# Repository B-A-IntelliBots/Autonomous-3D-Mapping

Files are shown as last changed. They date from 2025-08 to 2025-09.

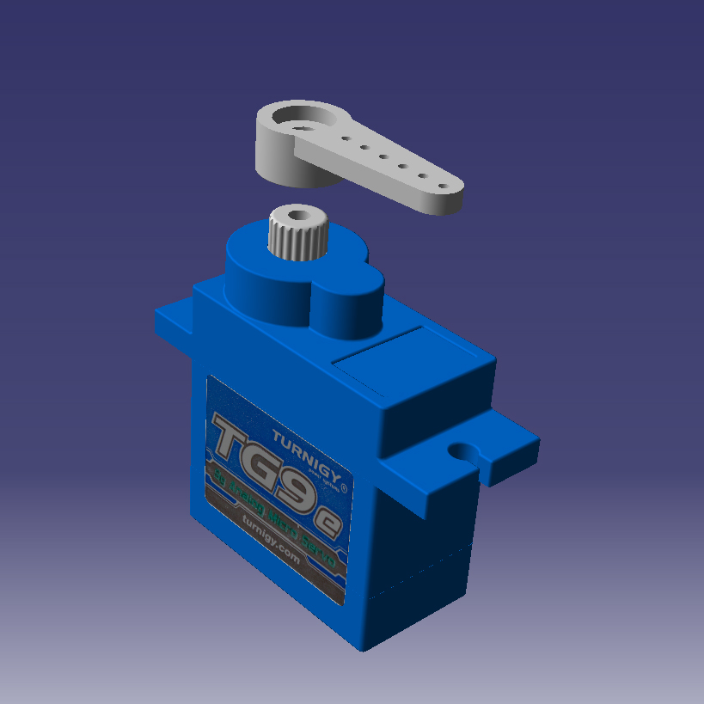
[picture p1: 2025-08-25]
src/CATIA PARTS/MICROSERVO/COMPONENT/TG9e.jpg

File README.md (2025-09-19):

<div align="center">

# Autonomous-3D-Mapping







</div>
  
## Overview
This project presents the development, modeling, and experimental validation of an
autonomous end to end indoor 3D reconstruction system using a monocular camera-
equipped differential-drive mobile robot. The goal is to control the platform through
the environment on a predefined path to capture images of the scene, then implement
the 3D reconstruction pipeline to build a virtual 3D Model of the space. A comprehensive dynamic model of the robot—encompassing mechanical and
electrical subsystems—was identified using input-output experiments and refined
via genetic algorithm optimization. The work incorporates the usage of FIR filter to
remove the noise from feedback signals (such as Encoders). The control architecture
employs a cascaded scheme with a Lyapunov-based outer loop and LQR-based inner
loop. To optimize performance metrics like path accuracy and energy efficiency, a
Predictive Neural Network (PNN) was trained to map target positions to optimal
control gains (𝐾𝑝 , 𝐾𝜃), enabling real-time adaptive control.
For the 3D reconstruction part, the hierarchical localization pipeline is implemented
to build a 3D model of the environment form a set of captured images. Empirical
benchmarking identified DISK (feature extractor) and LightGlue (matcher) as the
optimal vision components. These are fed into a reconstruction pipeline using
COLMAP and OpenMVS, producing high-quality 3D models of indoor scenes.
The system is implemented on a Raspberry Pi–Arduino platform running ROS and
validated both in simulation and on a real robot. The robot autonomously navigates
pre-defined discretized paths and captures structured image arcs at predefined waypoints.
This end-to-end framework bridges control theory with practical computer vision,
demonstrating how low-cost mobile robots can autonomously map environments
with high spatial accuracy using only monocular vision and optimized motion
planning.
> **TL;DR**: End-to-end autonomous 3D reconstruction of indoor environment using DDWMR
## ✨ Key Features
+ Integrating neural network-optimized hybrid control system
+ Deploying the optimal feature extractor and matcher—DISK and LightGlue—for dense and accurate 3D point cloud generation.
+ Identifying the robot system using "System-Identification" optimized through Genetic Algorithm
+ Filtering the Feedback signals with customized filter (FIR) for reliable localization and control.
## Demo
This video shows the end-to-end autonomous 3D reconstruction Process
<div align="center">
  <video src="https://github.com/user-attachments/assets/662caa91-467a-4c62-9c5a-49453e5b212f" controls loop></video>
</div>
<p align="center">
  <table>
    <tr>
      <!-- Left big image -->
      <td rowspan="2" width="40%">
        
      </td>
      <!-- Top row, two small images -->
      <td width="26%">
        
      </td>
      <td rowspan="2" width="34%">
        
      </td>
    </tr>
    <tr>
      <!-- Bottom row, two small images -->
      <td>
        
      </td>
    </tr>
  </table>
</p>

## Methodology

<div align="center">
  Description
</div>

### 1. Setting the Discretized Path:
Since the control algorithm is designed for a stabilization task—e.i., guiding the robot from its initial position to a target location—the first step in our project should be to define a discretized path through the relevant environment.

### 2. Navigating through the environment:
This step focuses on navigating the robot through the environment to capture images of surrounding objects. The process is carried out using the control scheme described in the following repo "https://github.com/B-A-IntelliBots/AI-optimized-LQR-Lyapunov-Control-System".

### 3. 3D Reconstrution:
This step involves constructing a 3D virtual model of the indoor environment using images captured by the robotic platform. The reconstruction process employs the ***DISK* Feature Extractor** and ***LIGHTGLUE* Feature Matcher** to achieve a highly accurate and densely detailed final output. The choice of this feature extractor–matcher combination is based on extensive comparative analysis supported by statistical metrics, as detailed in the following repository "https://github.com/B-A-IntelliBots/3D-Reconstruction".

---

## 🚀 Quick Start
### Prerequisites
- OS/Tooling: `Python ≥3.10` / `MATLAB R2014a` / `ROS1 noetic` / `CATIA V5R21`
- System deps: `cmake`
### Installation

+ #### Clone the repository:
  `$ git clone https://github.com/B-A-IntelliBots/Autonomous-3D-Mapping.git 3d-mapping`
  
---

## 📊 Results & Benchmarks
the performance of the proposed **System State-Space Identification** method—using MATLAB’s *System Identification Toolbox* in combination with a Genetic Algorithm (GA)—is validated according to the following criteria:

#### 🔹 1. Loss / Error Metrics

Quantitative performance is evaluated using:  
- **Euclidean Loss** (custom-defined residual error distance)

| Model Type | Euclidean Loss |
|---|---|
| GA-Optimized | *0.1189* |

#### 🔹 2. Computational Performance

- GA converged in **~[782] generations**  
- Execution time: **~[47 Sec]** on Intel i5 CPU
  
---

## 📁Project Structure
├── [src](https://github.com/B-A-IntelliBots/Autonomous-3D-Mapping/tree/main/src)/  # Core codes with the robot CATIA-designed components <br>
├── [data](https://github.com/B-A-IntelliBots/Autonomous-3D-Mapping/tree/main/data)/ # Sample datasets <br>
├── [results](https://github.com/B-A-IntelliBots/Autonomous-3D-Mapping/tree/main/results)/    # Plots and evaluation metrics <br>
├── README.md   # This file <br>

---

## 📖 Citation

```bibtex
@software{myproject2025,
  author    = {Ali Deeb, Bisher Alsaleh}, Supervised by: {Prof. Iyad Hatem}
  title     = {Autonomous 3D Mapping},
  year      = {2025},
  publisher = {GitHub},
  url       = {https://github.com/B-A-IntelliBots/Autonomous-3D-Mapping}
}

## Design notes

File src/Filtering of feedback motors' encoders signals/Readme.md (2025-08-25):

# Signal Noise Analysis and FIR Filtering

This section demonstrates how to identify and remove high-frequency noise from a sampled signal using MATLAB. The workflow involves:
---

## 1. Noise Detection Using FFT
To locate the source of noise in the signal, the raw signal is analyzed using its frequency spectrum. 
High-frequency components indicate the presence of noise.  

- **Script:** `Analysis_of_signal_frequency_spectrum.m`  
---
## 2. Design the Customized FIR filter

The FIR filter used in this project was designed using MATLAB's **Filter Design & Analysis Tool (fdatool)**. The design is customized to ensure the preservation of the DC component and its nearby frequency responses, while attenuating undesired higher frequencies.

---
## 3. FIR Filtering and Validation

Once the high-frequency noise is identified, an FIR filter is applied to the raw signal to remove unwanted components. The filtered signal is then validated in both time and frequency domains.  
- **Script:** `Applied_filter_validation.m`  
---
## Notes
- Replace `YourSampledSignalFile.txt` with your actual data file.  
- Replace `FilterObjectName` with the FIR filter object created using MATLAB’s Filter Designer.
- FFT plots use normalized frequency ranging from `-π` to `π` (rad/sample).

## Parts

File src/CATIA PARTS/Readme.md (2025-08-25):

# Robot Design – CATIA Parts

This Folder contains all the **CATIA (.CATPart)** files for the design of my mobile robot.
---

## 🛠️ Design Overview
The robot design includes:
- **Chassis** – Structural base of the robot.  
- **Camera & Servo Motor Holders** – Dedicated mounts for precise sensor and actuator placement.  
- **Electrical Component Distribution** – Organized layout that ensures balanced weight and shifts the **center of mass** toward the middle of the robot for improved stability.  
- **Pillar Holders** – Supporting structures that enhance robustness and modular assembly.
---

## 📂 File Content
- `.CATPart` files of the designed components.
- `FULL_ROBOT_DESIGN.CATProduct` is the complete assembly-ready structure for the robot’s main body and accessory mounts.

---

## 🙏 Acknowledgments
Special thanks to [GrabCAD](https://grabcad.com/) for facilitating the design process.  
Some electrical components used in this project were sourced from GrabCAD, where they were provided in **.CATPart** format.

---

## 📌 Notes
- The design can be adapted for different robot platforms depending on size and functional requirements.  
- All files are compatible with **CATIA V5** (and later versions).

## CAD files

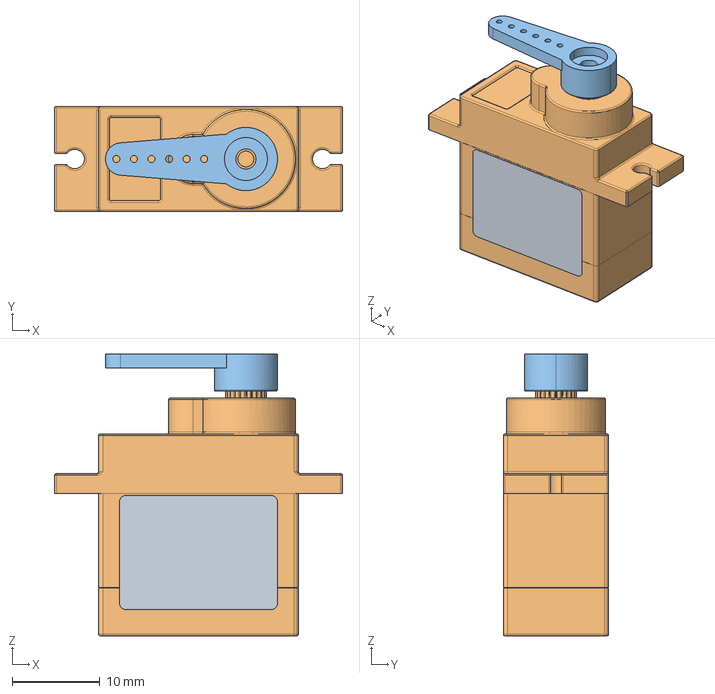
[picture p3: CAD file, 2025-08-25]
src/CATIA PARTS/MICROSERVO/COMPONENT/turnigy TG9e servo.stp
32.8 x 12.0 x 32.1 mm

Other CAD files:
src/CATIA PARTS/ALLCAMERA&SERVO/CAMSERV.CATProduct
src/CATIA PARTS/Bashing_3S1P_11.1V_5000mAH_60c.CATPart
src/CATIA PARTS/BreadBord.CATPart
src/CATIA PARTS/CAMERAHOLDER/CAMHOLD1.CATPart
src/CATIA PARTS/CAMERAHOLDER/CAMHOLD2.CATPart
src/CATIA PARTS/CAMERAHOLDER/CAMHOLD3.CATPart
src/CATIA PARTS/CAMERAHOLDER/HOLDER.CATProduct
src/CATIA PARTS/CAMERAHOLDER/RB_0005_PiCamV2.1.CATPart
src/CATIA PARTS/FULL_ROBOT_DESIGN.CATProduct
src/CATIA PARTS/L298/Motor Driver_L298N/CONDENSATORE SMD_220.CATPart
src/CATIA PARTS/L298/Motor Driver_L298N/DIODO M4_SMD.CATPart
src/CATIA PARTS/L298/Motor Driver_L298N/DISSIPATORE EXT_L298N.CATPart
src/CATIA PARTS/L298/Motor Driver_L298N/JUMPER.CATProduct
src/CATIA PARTS/L298/Motor Driver_L298N/LED_SMD 3.2x1.6mm.CATPart
src/CATIA PARTS/L298/Motor Driver_L298N/MC78M05 D-PAK.CATPart
src/CATIA PARTS/L298/Motor Driver_L298N/MJ-0 metal.CATPart
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

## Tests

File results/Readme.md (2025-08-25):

## 📊 Results  
### 1-Analysis and Filtration of Motors' Encoders Signals
After analyzing the frequency spectrum of the wheel angular velocity signals—measured by the encoders—using the Fourier Transform, it was observed that significant frequency components exist at higher frequencies. This is clearly shown in the following figure, where a relatively large amplitude appears at **ω = π/2**  
<div align="center">
  
</div>  
These high-frequency components introduce noise and oscillations into the signals.  

To mitigate this issue, an **Equiripple FIR filter** was designed with the following specifications:
- **Filter Type:** Lowpass FIR  
- **Design Method:** Equiripple  
- **Filter Order:** 42  
- **Passband Frequency (`wp`):** 0.031 (normalized 0–1)  
- **Stopband Frequency (`ws`):** 0.2 (normalized 0–1)  
- **Passband Ripple (`Apass`):** 1 dB  
- **Stopband Attenuation (`Astop`):** 120 dB  
- **Stability:** Yes (Direct-Form FIR)

FIR_Specs

This configuration ensures the preservation of the DC component and its nearby frequency responses, while attenuating undesired higher frequencies.

The effect of the filter is evident in the results. After applying the designed Equiripple FIR filter to the original signal, the filtered output—shown in the following image—demonstrates a steadily increasing trend with significantly reduced oscillations, making it a more reliable feedback signal for the lookup control objective.
<div align="center">

</div>  
Furthermore, the frequency spectrum of the filtered signal confirms the successful suppression of high-frequency noise as follows:
<div align="center">

</div>

### 2- Evaluating the Accuracy of System Identification optimized through Genetic Algorithm
<section>
  <p>
    A sequence of input step signals with varying amplitudes is applied independently to each motor
    (<i>V</i><sub>r</sub>, <i>V</i><sub>l</sub>) to record the mobile robot states
    [<i>w</i><sub>r</sub>, <i>w</i><sub>l</sub>, <i>i</i><sub>r</sub>, <i>i</i><sub>l</sub>]
    in response to these inputs.
  </p>

  <p>
    These input–output relationships are modeled using MATLAB’s
    <strong>System Identification Toolbox</strong>, ensuring that each identified transfer function
    matches its theoretically defined number of poles and zeros.
  </p>
  
  The figure below illustrates the **measured vs. identified responses** of right wheel angular velocity (<i>w</i><sub>r</sub>) in RPM to the right motor input voltage (<i>V</i><sub>r</sub>).
System_Identification

  <p>
    The <strong>objective function</strong> is defined as the Euclidean distance between:
  </p>
  <ul>
    <li>
      a reference vector <span><i>v</i> ∈ ℝ<sup>12</sup></span>, which collects all numerical terms produced by the system identification; and the equations obtained from substituting the six system variables.
  </ul>

  having an initial guess that lies within the vicinity of the optimal solution can significantly reduce the 
number of generations required and increase the likelihood of successfully reaching 
the global minimum. Luckily, this initial guess is taken to be a preliminary solution 
for the genetic algorithm from previous practical endeavors to find the interior parameters of the mechanical and electrical parts. Through this formulation, the **Genetic Algorithm (GA)** converges to an optimal solution. The GA’s hyperparameters are carefully preset and tuned to minimize the loss function, leading to a sharp decline that reaches the **lowest global minimum value of 0.1189 within 782 generations**, as shown in the following Table and figure: <br>
  Trainingpng

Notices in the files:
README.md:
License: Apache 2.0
